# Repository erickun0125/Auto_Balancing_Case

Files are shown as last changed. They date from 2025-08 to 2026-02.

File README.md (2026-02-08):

# Auto Balancing Case

***A self-balancing wheeled suitcase powered by sim-to-real reinforcement learning***







<p align="center">
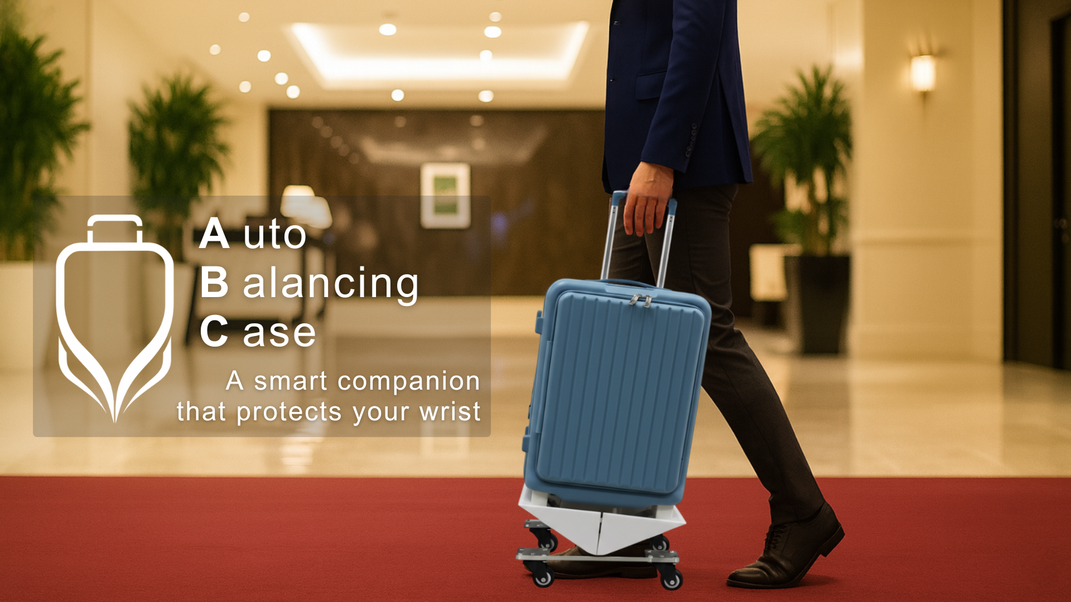
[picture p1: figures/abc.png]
Auto Balancing Case — overview
  
</p>

## Motivation

Conventional wheeled suitcases tilt forward on carpets, ramps, and uneven terrain, forcing users to apply excessive **wrist torque** to keep them upright. This increases fatigue during prolonged travel and makes handling uncomfortable — yet most existing solutions rely on complex vision-based systems or powered wheels that add weight and cost.

This project takes a different approach: instead of fighting gravity with brute force, we **shift the suitcase's center of mass** in real time using a learned policy, eliminating the need for additional user effort entirely.

<p align="center">
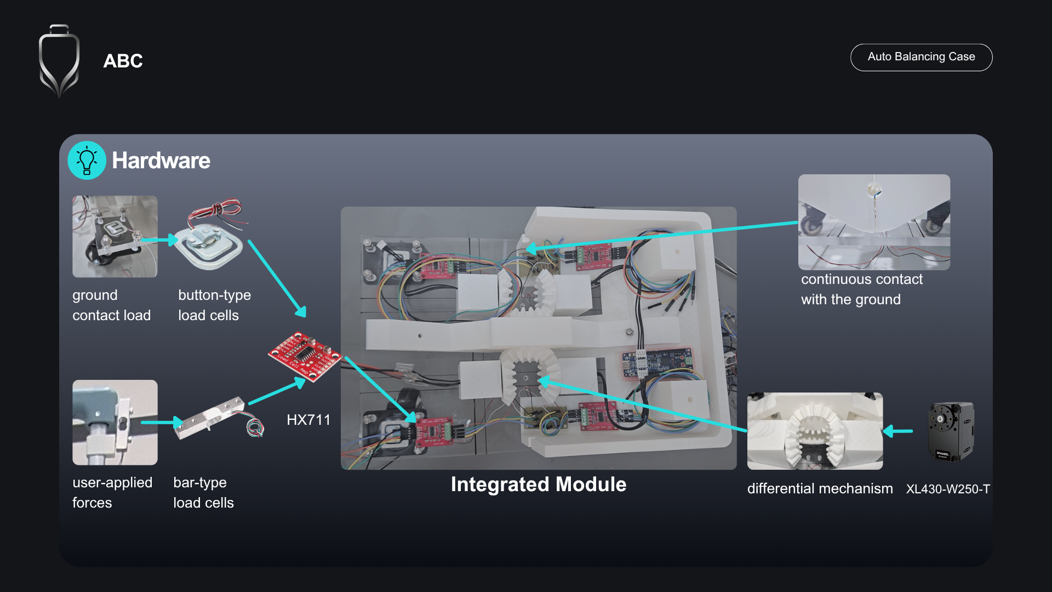
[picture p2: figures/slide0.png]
Presentation slide 1
  
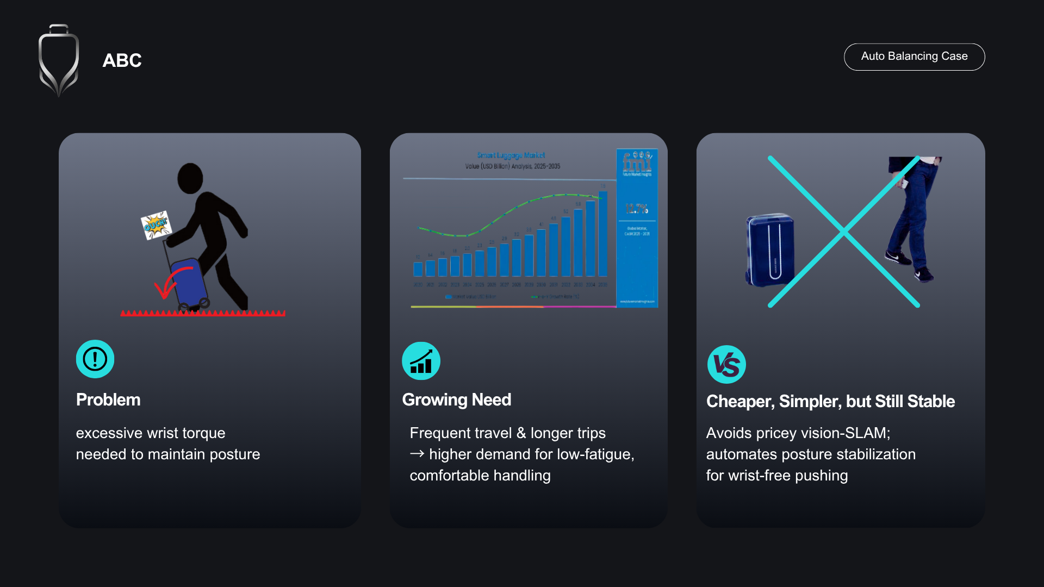
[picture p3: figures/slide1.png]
Presentation slide 2
  
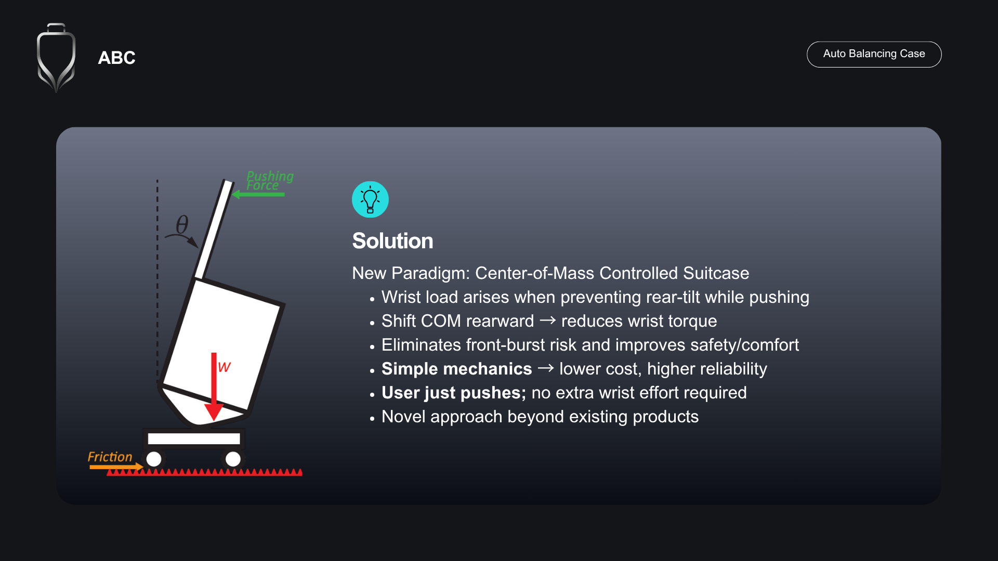
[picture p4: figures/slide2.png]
Presentation slide 3
  
</p>

## Highlights

- **End-to-end pipeline**: CAD design → URDF → Isaac Lab simulation → PPO training → real hardware deployment
- **Sim-to-real transfer** with domain randomization (external forces, velocity pushes, mass variation)
- **Real-time 50 Hz control** with 4 Dynamixel XL430 motors and 5 HX711 load cells
- **Custom reward engineering** with 9 reward terms for contact force balancing
- **2,048 parallel environments**, [256, 128, 64] actor-critic network trained over 15K iterations
- **Multi-sensor fusion**: wheel contact forces + handle force + joint state + action history → 32-dim observation

## Table of Contents

- [Motivation](#motivation)
- [System Overview](#system-overview)
- [Architecture](#architecture)
- [Technical Deep Dive](#technical-deep-dive)
- [Results](#results)
- [Future Work](#future-work)
- [Getting Started](#getting-started)
- [Usage](#usage)
- [Project Structure](#project-structure)
- [Key Specifications](#key-specifications)
- [Contributors](#contributors)
- [Acknowledgments](#acknowledgments)
- [License](#license)

## System Overview

### Core Idea — Mass-Shifting Upper Body

Rather than adding powered wheels or complex stabilization mechanisms, the suitcase features a **mass-shifting upper body** connected to the wheeled base via a single revolute (hinge) joint. When the suitcase begins to tilt — due to a ramp, carpet, or user push — a learned RL policy commands the upper body to shift its center of gravity rearward, **preventing the initial tip and eliminating the wrist torque** the user would otherwise need to apply.

### End-to-End Pipeline

The Auto Balancing Case learns to keep the suitcase upright against external disturbances using this single actuated hinge joint. A PPO policy is trained in NVIDIA Isaac Lab simulation across 2,048 parallel environments, then deployed directly on real hardware via a Python bridge running at 50 Hz — no fine-tuning on real hardware required.

```mermaid
graph LR
    A["CAD Design<br/>SolidWorks"] --> B["URDF Model"]
    B --> C["USD Conversion<br/>Isaac Lab"]
    C --> D["RL Training<br/>PPO / 2048 envs"]
    D --> E["Trained Policy<br/>.pt checkpoint"]
    E --> F["Sim2Real Bridge<br/>Python 50Hz"]
    F --> G["Hardware<br/>4 Motors + 5 Sensors"]
```

## Architecture

### System Architecture

<p align="center">
  System architecture block diagram
</p>

<details>
<summary>Text version (Mermaid)</summary>

```mermaid
graph TB
    subgraph Simulation ["Simulation (Isaac Lab)"]
        ENV["2048 Parallel Envs<br/>PhysX 200Hz"] --> PPO["PPO Training<br/>RSL-RL"]
        PPO --> POLICY["Actor-Critic Network<br/>256 → 128 → 64, ELU"]
    end

    subgraph Bridge ["Sim2Real Bridge (Python)"]
        CONFIG["Config Manager<br/>YAML + Platform Override"] --> CTRL["AutoBalancingCaseBridge<br/>50Hz Control Loop"]
        CTRL --> PI["Policy Interface<br/>PyTorch Inference"]
        CTRL --> MI["Motor Interface<br/>Dynamixel Protocol 2.0"]
        CTRL --> SI["Sensor Interface<br/>Arduino Serial CSV"]
    end

    subgraph Hardware ["Hardware"]
        MI --> MOTORS["4× Dynamixel XL430<br/>2 ports, ±θ"]
        SI --> ARDUINO["Arduino Mega<br/>6× HX711 ADC"]
        ARDUINO --> LC["5 Load Cells<br/>4 wheel + 1 handle"]
    end

    POLICY -.->|".pt checkpoint"| PI
```
</details>

### Observation Space

Each timestep produces an 8-dimensional observation. With 4-step history, the policy sees a **32-dimensional input**.

| Index | Component | Dims | Source | Description |
|---|---|---|---|---|
| 0 | `joint_pos` | 1 | Motor encoder | Relative joint position (rad) |
| 1 | `joint_vel` | 1 | Motor encoder | Joint velocity (rad/s) |
| 2 | `prev_action` | 1 | Policy output | Previous action [−0.5, 0.5] |
| 3–6 | `wheel_forces` | 4 | HX711 load cells | Per-wheel contact force (N) [FR, RR, FL, RL] |
| 7 | `handle_force` | 1 | HX711 load cell | External handle force (N) |

### Reward Engineering

9 reward terms shape the balancing behavior:

| Reward Term | Weight | Type | Purpose |
|---|---|---|---|
| `is_alive` | +1.0 | Bonus | Survival incentive |
| `is_terminated` | −100.0 | Penalty | Large termination punishment |
| `flat_orientation_l2` | −10.0 | Penalty | Keep platform horizontal |
| `ang_vel_xy_l2` | −0.5 | Penalty | Minimize angular oscillation |
| `hinge_pos_deviation` | −5.0 | Penalty | Stay near default joint position |
| `desired_contacts` | −10.0 | Penalty | Maintain all 4 wheel contacts |
| `wheel_contact_balance` | +3.0 | Reward | Equal force distribution (exp(−variance/mean)) |
| `wheel_contact_min_max` | −0.1 | Penalty | Reduce max–min force difference |
| `action_rate_l2` | −0.01 | Penalty | Smooth actions |

## Technical Deep Dive

### Sim-to-Real Transfer

<p align="center">
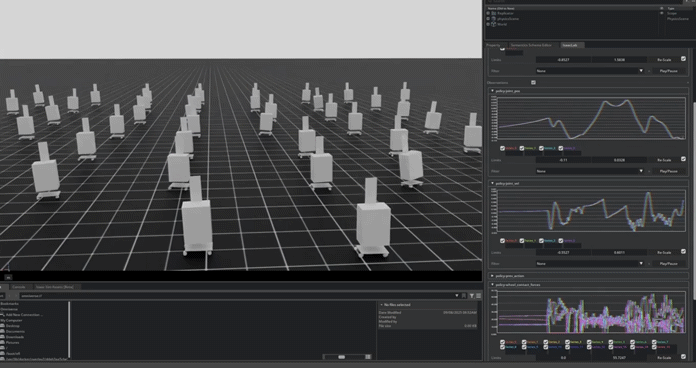
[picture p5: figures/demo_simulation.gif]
Isaac Lab training — 2048 parallel environments
  
  <br/>
  <em>PPO training in NVIDIA Isaac Lab with 2,048 parallel environments</em>
</p>

The policy transfers from simulation to real hardware without fine-tuning. Key strategies:

- **Domain randomization**: 4 disturbance groups applied to partitioned environment subsets
  - Velocity-based pushes (x-axis, randomized range)
  - External wrenches with position offsets
  - Directional force/torque application
  - Combined push + wrench events
- **Raw observations**: No normalization applied — same value ranges in sim and real hardware
- **Observation noise injection**: Additive uniform noise on joint position (±0.005), velocity (±0.05), and forces (±0.01)

### Real-Time Control Pipeline

<p align="center">
  50 Hz real-time control flow
</p>

The 50 Hz control loop in `AutoBalancingCaseBridge` executes 7 steps per cycle (20 ms budget):

1. **Read motor state** — Position and velocity via Dynamixel Protocol 2.0 (2 serial ports)
2. **Read sensor state** — 5 load cell forces via Arduino serial CSV
3. **Construct observation** — 8-dim vector with relative joint position (Isaac Lab compatible)
4. **Update history** — Append to 4-step deque (oldest entries dropped)
5. **Run policy inference** — PyTorch forward pass on 32-dim input (CPU, ~1 ms)
6. **Clip and send command** — Action clipped to [−0.5, 0.5] rad → 4 motors (+θ, +θ, −θ, −θ)
7. **Maintain timing** — Sleep for remainder of 20 ms cycle; warn if >10 ms overrun

**Safety systems**: Emergency stop at 0.51 rad tilt, watchdog timeout at 1.0 s.

### Hardware Design

<p align="center">
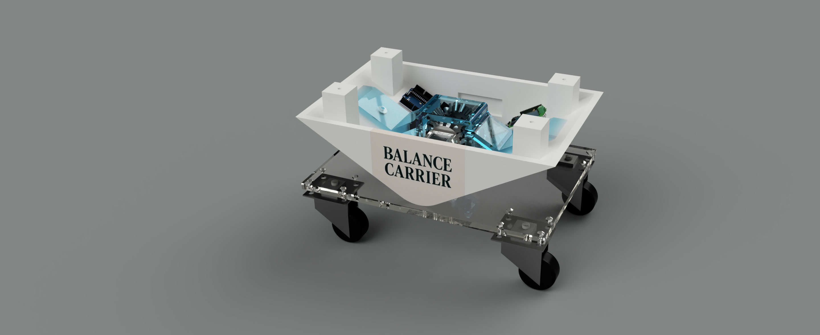
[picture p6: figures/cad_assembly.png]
CAD assembly design
  
</p>

<p align="center">
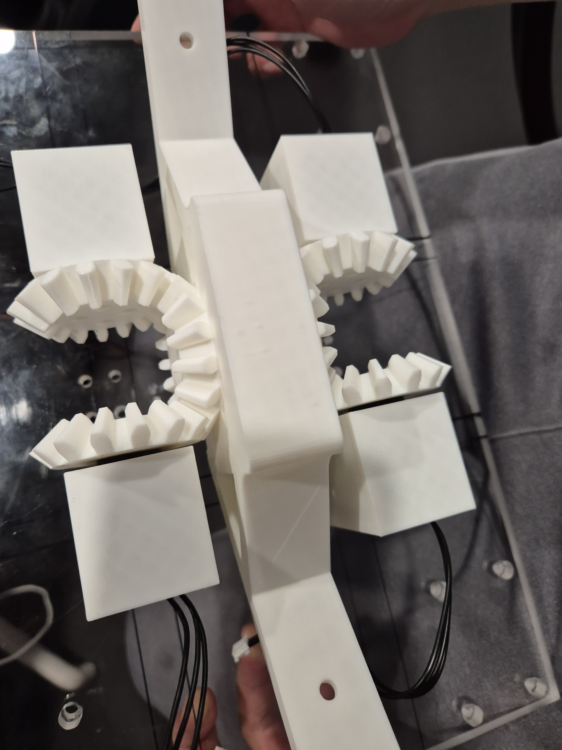
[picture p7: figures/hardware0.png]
Hardware photo 1
  
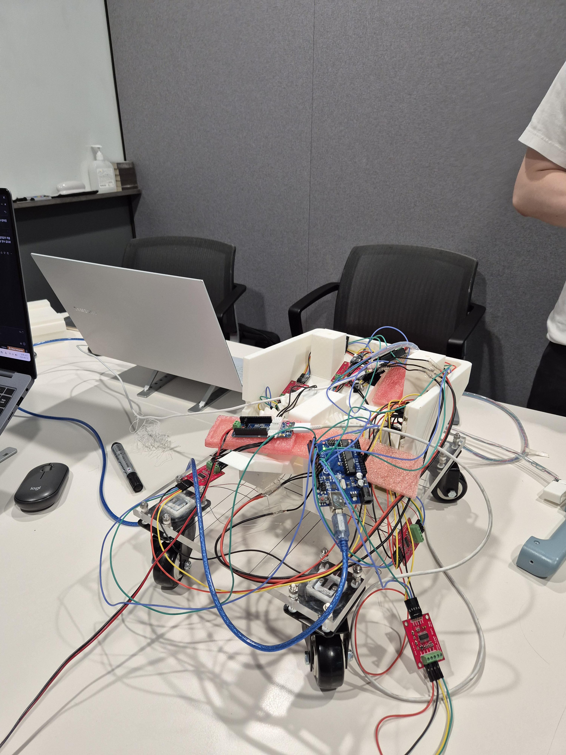
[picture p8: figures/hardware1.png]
Hardware photo 2
  
</p>

<p align="center">
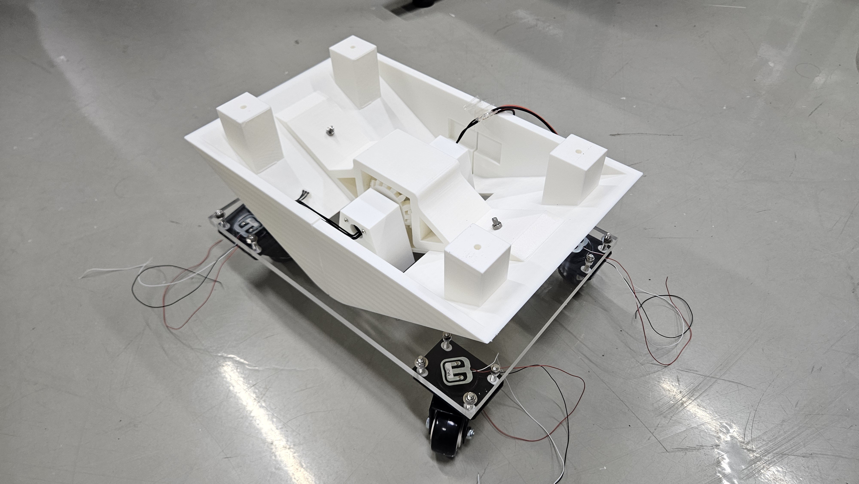
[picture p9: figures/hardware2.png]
Hardware photo 3
  
</p>

- **Base platform**: 4-wheel mobile base (~0.98 kg, 36 cm × 23 cm)
- **Luggage body**: ~5.6 kg connected via single revolute joint (Y-axis, ±30°)
- **Motors**: 4× Dynamixel XL430-W250 (Protocol 2.0, 57600 baud, center=2048)
- **Sensors**: 5× HX711 load cells (4 wheel + 1 handle), Arduino at 115200 baud / 10 Hz
- **Custom parts**: 3D-printed differential bevel gears, motor support, gearbox wing

## Results

<p align="center">
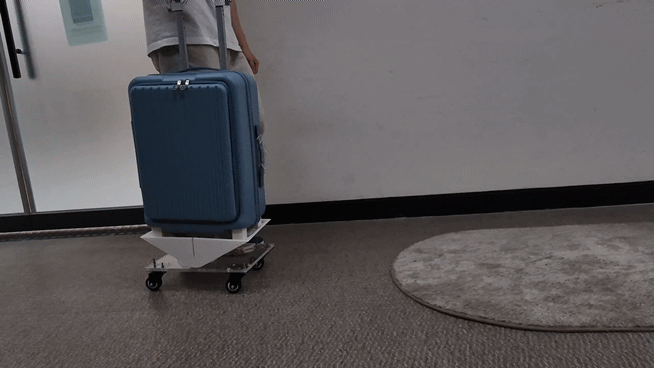
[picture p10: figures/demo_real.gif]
Real hardware demo — self-balancing on uneven terrain
  
  <br/>
  <em>Real-time balancing on uneven terrain — zero additional wrist torque required</em>
</p>

- **Zero additional wrist torque** — users reported no need for extra effort to keep the suitcase upright on rough terrain
- **Responsive disturbance recovery** — the policy reacts to pushes and slope changes within one control cycle (20 ms)
- **Direct sim-to-real transfer** — the trained policy deployed on real hardware without any fine-tuning or adaptation
- **Modular integration** — the mass-shifting mechanism can be integrated into existing suitcase frames without structural redesign

## Future Work

- Quantitative handling-effort measurement (e.g., wrist torque sensor comparison with/without balancing)
- Extension to wheeled carts and logistics platforms
- On-device inference optimization (microcontroller deployment, removing laptop dependency)

## Getting Started

### Prerequisites

- Python 3.8+
- NVIDIA GPU with CUDA (for Isaac Lab training only)
- Dynamixel XL430 motors + Arduino Mega (for hardware deployment)

### Installation

```bash
# Clone the repository
git clone https://github.com/erickun0125/Auto_Balancing_Case.git
cd Auto_Balancing_Case

# Install sim2real bridge dependencies
cd suitcase_sim2real
pip install -r requirements.txt

# Isaac Lab setup (for training only)
# Follow NVIDIA Isaac Lab installation guide, then register custom environments
```

## Usage

### Training (Simulation)

```bash
cd suitcase_learning
./isaaclab.sh -p scripts/train.py --task Isaac-Suitecase-Flat-v0 --num_envs 2048
```

### Evaluation (Simulation)

```bash
./isaaclab.sh -p scripts/play.py --task Isaac-Suitecase-Flat-Play-v0 \
  --checkpoint trained_models/model_49999.pt
```

### Hardware Deployment

```bash
cd suitcase_sim2real/src

# Step 1: Calibrate load cells (first time only)
python run_policy.py --mode calibrate

# Step 2: Run single episode (4000 steps = 8 seconds)
python run_policy.py --mode episode

# Step 3: Run continuously until Ctrl+C
python run_policy.py --mode continuous

# Custom config
python run_policy.py --config path/to/config.yml --mode episode
```

## Project Structure

```
Auto_Balancing_Case/
├── suitcase_learning/               # Isaac Lab simulation & RL training
│   ├── envs/                        #   Custom environment & MDP definitions
│   │   ├── suitecase_env_cfg.py     #     Environment config, rewards, observations
│   │   └── mdp_for_ABC.py           #     Custom MDP functions (forces, events)
│   ├── agents/                      #   PPO hyperparameters
│   │   └── rsl_rl_ppo_cfg.py
│   ├── scripts/                     #   Training & evaluation scripts
│   ├── assets/                      #   USD robot model for Isaac Lab
│   └── trained_models/              #   Checkpoints & exported policies
│
├── suitcase_sim2real/               # Real hardware deployment
│   ├── src/                         #   Main bridge code
│   │   ├── run_policy.py            #     CLI entry point (calibrate/episode/continuous)
│   │   ├── bridge.py                #     50Hz control loop orchestrator
│   │   ├── policy_interface.py      #     RSL-RL model loading & inference
│   │   ├── motor_interface.py       #     4-motor control (2 serial ports)
│   │   ├── sensor_interface.py      #     5 load cell sensor interface
│   │   ├── config_manager.py        #     YAML config with platform overrides
│   │   └── config/interface_config.yml    # All hardware/policy settings
│   ├── firmware/                    #   Arduino firmware (HX711 ADC readout)
│   └── requirements.txt
│
├── suitcase_model/                  # CAD models & URDF robot descriptions
│   ├── urdf/                        #   Robot URDF definitions
│   ├── stl/                         #   3D-printable mechanical parts
│   └── ros_package/                 #   ROS-compatible URDF package
│
├── docs/media/                      # Demo videos, screenshots, diagrams
├── LICENSE
└── README.md
```

## Key Specifications

### Training Configuration

| Parameter | Value |
|---|---|
| Algorithm | PPO (Proximal Policy Optimization) |
| Framework | RSL-RL on NVIDIA Isaac Lab |
| Parallel Environments | 2,048 |
| Physics Frequency | 200 Hz (dt = 0.005 s) |
| Control Frequency | 50 Hz (decimation = 4) |
| Episode Length | 8.0 s (4,000 steps) |
| Network Architecture | Actor & Critic: [256, 128, 64], ELU |
| Observation Dim | 32 (8 per timestep × 4 history) |
| Action Dim | 1 (joint position target, rad) |
| Learning Rate | 1e-3 |
| Max Iterations | 15,000 |
| Discount Factor (γ) | 0.99 |
| GAE Lambda (λ) | 0.95 |

### Hardware Specifications

| Component | Detail |
|---|---|
| Motors | 4× Dynamixel XL430-W250 |
| Motor Protocol | Protocol 2.0, 57600 baud, 2 serial ports |
| Load Cells | 5× HX711 (4 wheel + 1 handle) |
| Sensor MCU | Arduino Mega, 115200 baud, 10 Hz |
| Control Loop | 50 Hz (20 ms cycle) |
| Joint Range | ±0.5 rad (±28.6°) |
| Emergency Stop | 0.51 rad tilt threshold |
| System Mass | ~6.5 kg |

## Contributors

| Name | Contributions |
|---|---|
| **@erickun0125** | IsaacLab Environment Setting, Sim2Real Bridge, RL Agent Training |
| **@toddjrdl** | CAD Model Design, Hardware Integration, Policy Deployment |
| **@juninjae** | Actuator & Sensor System Design, System Integration, Real World Deployment |

## Acknowledgments

- [NVIDIA Isaac Lab](https://isaac-sim.github.io/IsaacLab/) — GPU-accelerated physics simulation & RL framework
- [RSL-RL](https://github.com/leggedrobotics/rsl_rl) — PPO implementation from Robotic Systems Lab (ETH Zurich)
- [Robotis Dynamixel](https://www.robotis.us/) — XL430 motor hardware and SDK
- [PyTorch](https://pytorch.org/) — Neural network framework
- [HX711_ADC](https://github.com/olkal/HX711_ADC) — Arduino load cell library

## License

This project is licensed under the MIT License — see the [LICENSE](LICENSE) file for details.

---

*Built at Seoul National University. Demonstrates a complete robotics development pipeline from concept to real-world deployment.*

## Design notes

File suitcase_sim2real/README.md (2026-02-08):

# Sim2Real Deployment

Deploys the Isaac Lab-trained PPO policy on real Auto Balancing Case hardware at 50 Hz.

## Directory Structure

```
suitcase_sim2real/
├── src/                             # Python bridge code
│   ├── run_policy.py                #   CLI entry point (calibrate/episode/continuous)
│   ├── bridge.py                    #   50 Hz control loop orchestrator
│   ├── policy_interface.py          #   RSL-RL model loading & inference
│   ├── motor_interface.py           #   Dynamixel XL430 motor control (4 motors, 2 ports)
│   ├── sensor_interface.py          #   HX711 load cell interface (5 channels via Arduino)
│   ├── config_manager.py            #   YAML config with platform overrides
│   └── config/interface_config.yml  #   All hardware/policy settings
├── firmware/                        # Arduino firmware
│   └── hx711_load_cells/
│       └── hx711_load_cells.ino     #   6× HX711 ADC readout, CSV at 10 Hz
└── requirements.txt                 # Python dependencies
```

## Hardware

| Component | Details |
|---|---|
| Motors | 4× Dynamixel XL430-W250, Protocol 2.0, 57600 baud, 2 serial ports |
| Sensors | 5× HX711 load cells (4 wheel + 1 handle), Arduino Mega, 115200 baud |
| Control | 50 Hz real-time loop, ±0.5 rad action range, 0.51 rad emergency stop |

## Quick Start

```bash
cd src
pip install -r ../requirements.txt

python run_policy.py --mode calibrate    # First-time load cell calibration
python run_policy.py --mode episode      # Single episode (8 seconds)
python run_policy.py --mode continuous   # Run until Ctrl+C
```

## Platform Configuration

Serial ports are auto-configured via `platform_overrides` in `config/interface_config.yml`:
- **Windows**: COM7 (sensor), COM11/COM12 (motors)
- **Linux**: /dev/ttyACM0 (sensor), /dev/ttyUSB0/ttyUSB1 (motors)

## Safety

- Emergency stop at 0.51 rad tilt threshold
- Watchdog timeout at 1.0 second
- Motors return to center position on shutdown
- Torque disabled after safe stop

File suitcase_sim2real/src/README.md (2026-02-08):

# Sim2Real Bridge — Source Code

This directory contains the Python bridge that deploys the Isaac Lab-trained RL policy on real hardware at 50 Hz.

## Files

| File | Description |
|---|---|
| `run_policy.py` | CLI entry point (`calibrate`, `episode`, `continuous` modes) |
| `bridge.py` | Main 50 Hz control loop orchestrator |
| `policy_interface.py` | RSL-RL ActorCritic model loading and inference |
| `motor_interface.py` | Dynamixel XL430 motor control (4 motors, 2 serial ports) |
| `sensor_interface.py` | HX711 load cell sensor interface (5 channels via Arduino) |
| `config_manager.py` | YAML configuration loader with platform overrides |
| `config/interface_config.yml` | Hardware and policy configuration |

## Quick Start

```bash
# Install dependencies
pip install -r ../requirements.txt

# Calibrate load cells (first time only)
python run_policy.py --mode calibrate

# Run single episode (4000 steps = 8 seconds)
python run_policy.py --mode episode

# Run continuously until Ctrl+C
python run_policy.py --mode continuous
```

See the [project README](../../README.md) for full documentation.

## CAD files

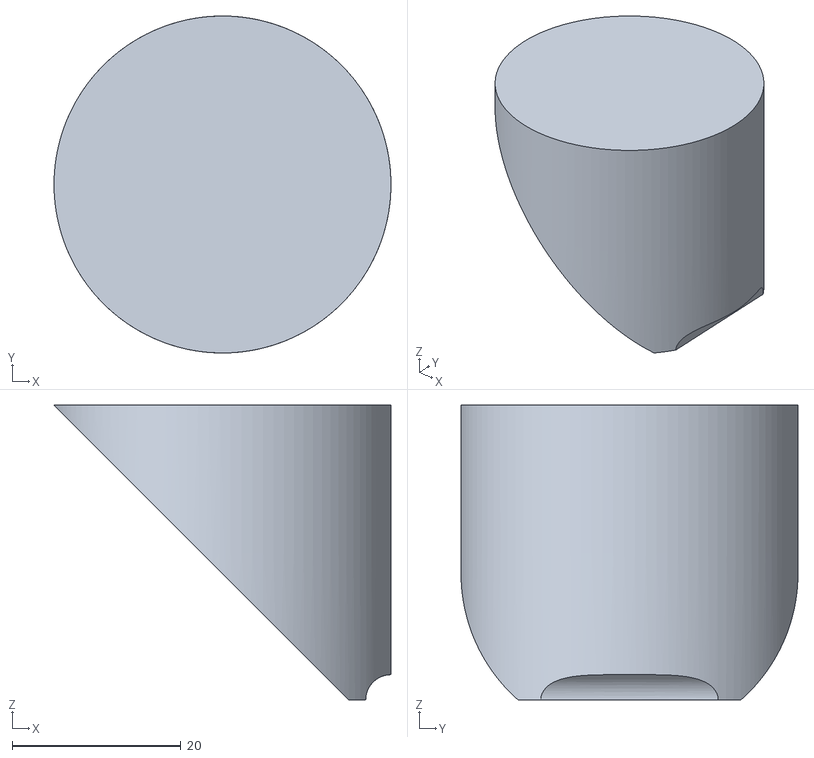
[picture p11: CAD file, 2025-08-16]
suitcase_model/ros_package/meshes/FR_wheelbase_1.stl
40.0 x 40.0 x 35.0

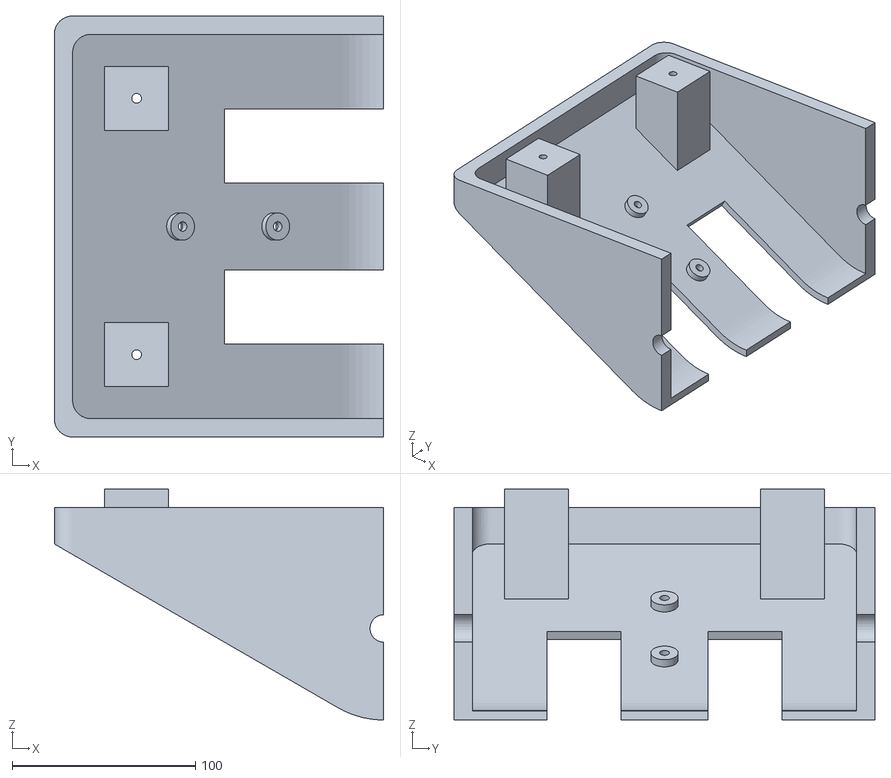
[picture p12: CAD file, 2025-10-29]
suitcase_model/stl/bottom_half.stl
180.0 x 230.0 x 126.2

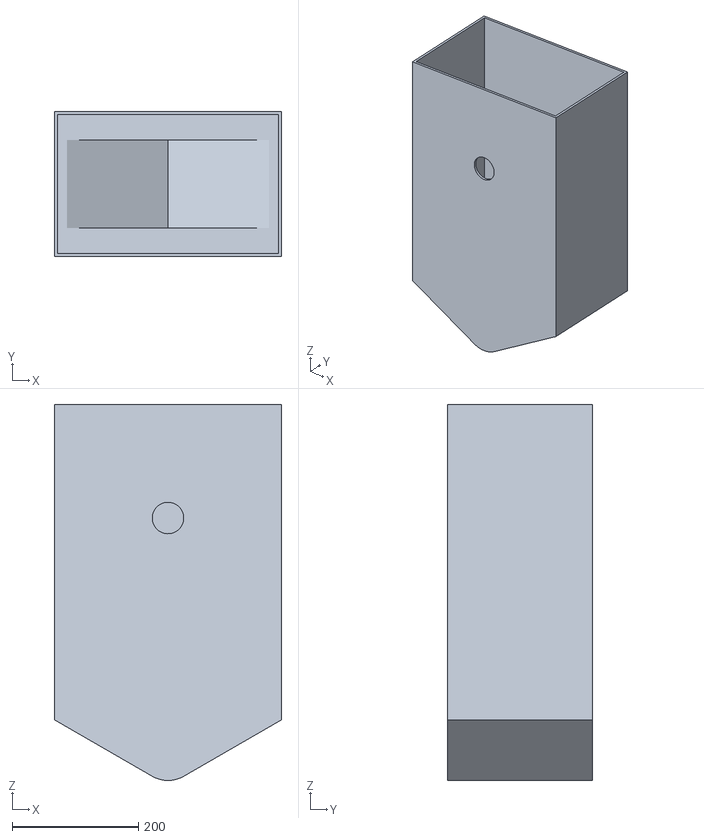
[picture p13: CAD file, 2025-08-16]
suitcase_model/ros_package/meshes/luggage_case_1.stl
360.0 x 230.0 x 596.2

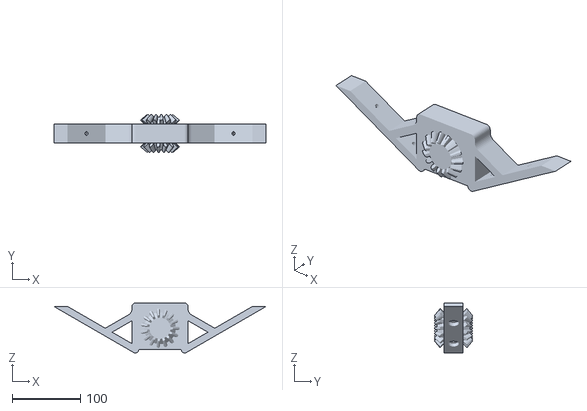
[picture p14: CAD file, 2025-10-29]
suitcase_model/stl/gearbox_wing.stl
309.9 x 55.0 x 73.0

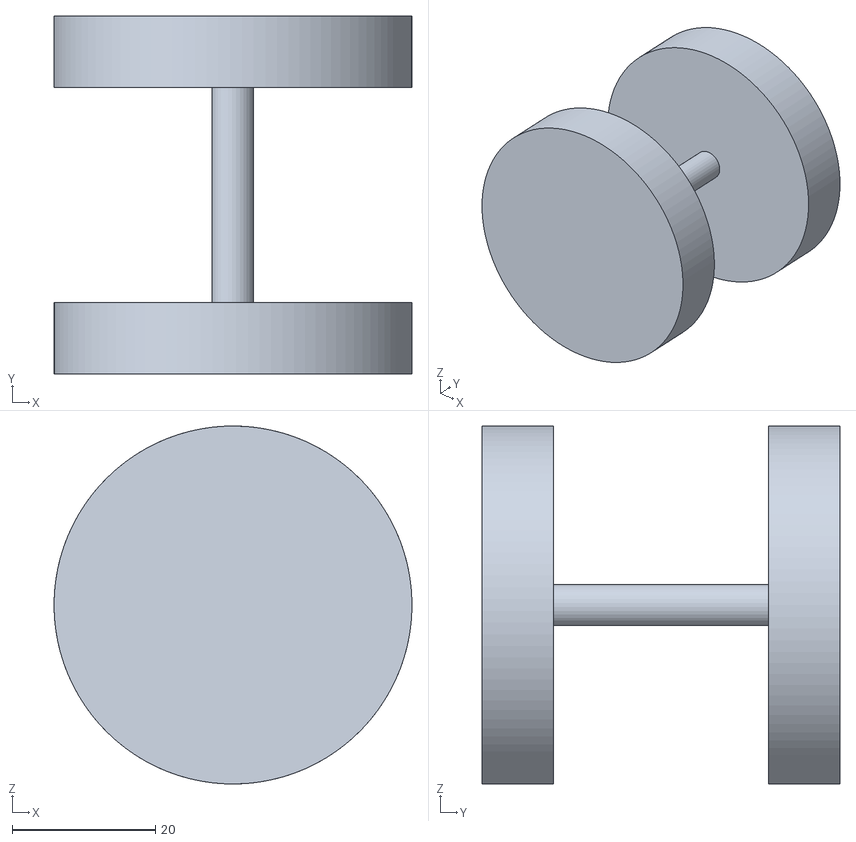
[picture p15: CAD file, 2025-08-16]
suitcase_model/ros_package/meshes/FL_wheel_1.stl
50.0 x 50.0 x 50.0

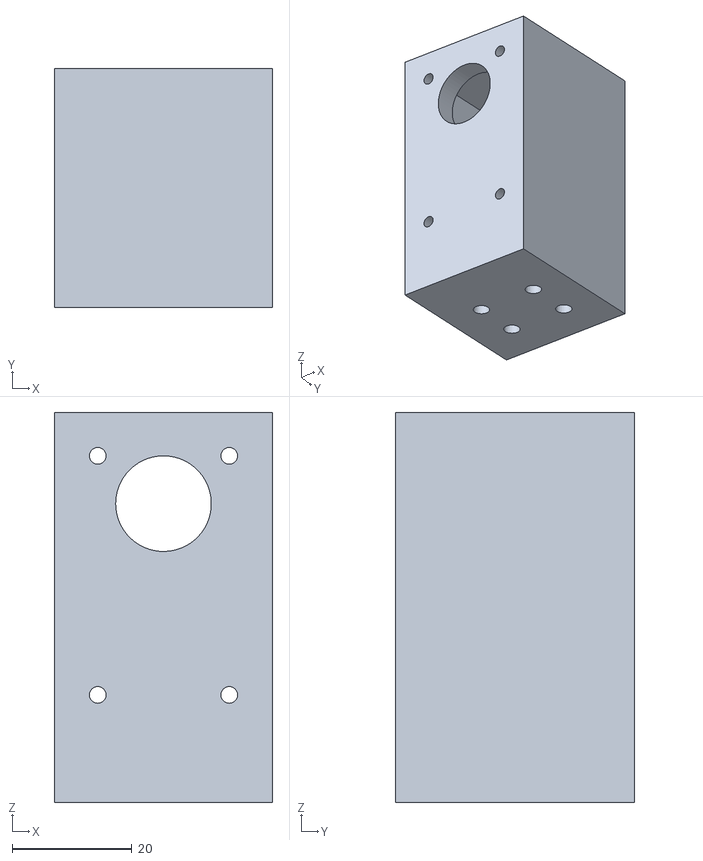
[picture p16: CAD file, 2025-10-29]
suitcase_model/stl/motor_support.stl
36.5 x 40.0 x 65.2

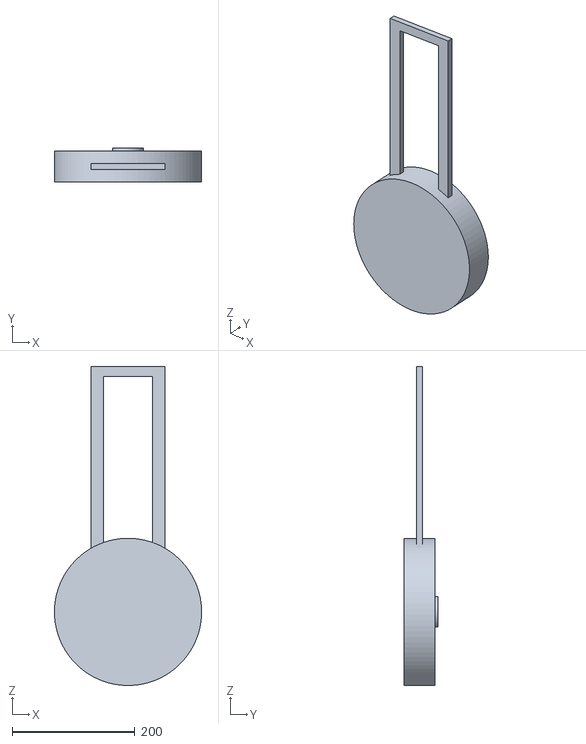
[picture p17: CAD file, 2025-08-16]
suitcase_model/ros_package/meshes/rotating_handle_1.stl
239.9 x 55.0 x 520.0

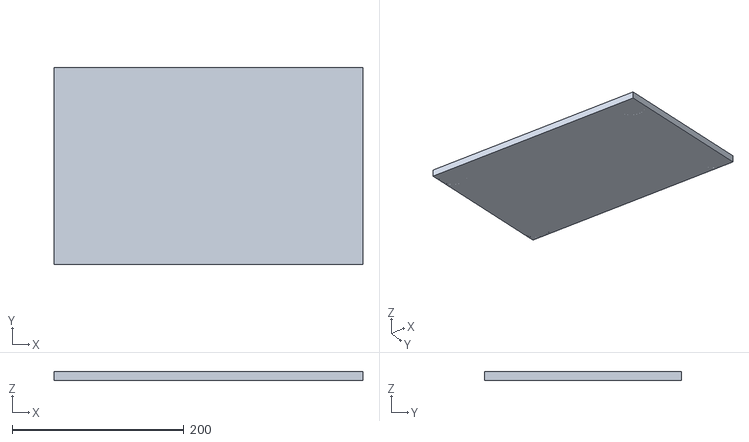
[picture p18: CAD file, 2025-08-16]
suitcase_model/ros_package/meshes/base_link.stl
360.0 x 230.0 x 10.0

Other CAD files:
suitcase_model/ros_package/meshes/FL_wheelbase_1.stl
suitcase_model/ros_package/meshes/RL_wheelbase_1.stl
suitcase_model/ros_package/meshes/RL_wheel_1.stl
suitcase_model/ros_package/meshes/RR_wheel_1.stl
suitcase_model/ros_package/meshes/RR_wheelbase_1.stl
suitcase_model/ros_package/meshes/FR_wheel_1.stl

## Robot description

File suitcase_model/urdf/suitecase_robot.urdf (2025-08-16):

<?xml version="1.0" ?>
<robot name="Auto_Balancing_Case" xmlns:xacro="http://www.ros.org/wiki/xacro">

  <!-- simple inline material since xacro includes are removed -->
  <material name="silver">
    <color rgba="0.75 0.75 0.75 1.0"/>
  </material>

  
<link name="base_link">
  <inertial>
    <origin xyz="0.17999999999999997 0.115 0.005003006827026274" rpy="0 0 0"/>
    <mass value="0.9847218407587564"/>
    <inertia ixx="0.004346" iyy="0.010634" izz="0.014964" ixy="-0.0" iyz="0.0" ixz="-0.0"/>
  </inertial>
  <visual>
    <origin xyz="0.18 0.115 0.005" rpy="0 0 0"/>
    <geometry>
      <box size="0.36 0.23 0.01"/>
    </geometry>
    <material name="silver"/>
  </visual>
  <collision>
    <origin xyz="0.18 0.115 0.005" rpy="0 0 0"/>
    <geometry>
      <box size="0.36 0.23 0.01"/>
    </geometry>
  </collision>
</link>

<link name="handle">
  <inertial>
    <origin xyz="0.0 0.0 0.0" rpy="0 0 0"/>
    <mass value="0.0"/>
    <inertia ixx="0.0" iyy="0.0" izz="0.0" ixy="-0.0" iyz="0.0" ixz="-0.0"/>
  </inertial>
  <visual>
    <origin xyz="0.0 0.005 0.35" rpy="0 0 0"/>
    <geometry>
      <box size="0.15 0.01 0.35"/>
    </geometry>
    <material name="silver"/>
  </visual>
  <collision>
    <origin xyz="0.0 0.005 0.35" rpy="0 0 0"/>
    <geometry>
      <box size="0.15 0.01 0.35"/>
    </geometry>
  </collision>
</link>

<link name="FR_wheelbase_1">
  <inertial>
    <origin xyz="0.004854891037663869 0.0 -0.01224396424044122" rpy="0 0 0"/>
    <mass value="0.026348088954006088"/>
    <inertia ixx="5e-06" iyy="4e-06" izz="5e-06" ixy="-0.0" iyz="0.0" ixz="1e-06"/>
  </inertial>
</link>

<link name="RR_wheelbase_1">
  <inertial>
    <origin xyz="0.004821350892733667 -2.7755575615628914e-17 -0.012195503618703826" rpy="0 0 0"/>
    <mass value="0.02614973311170209"/>
    <inertia ixx="5e-06" iyy="4e-06" izz="5e-06" ixy="-0.0" iyz="0.0" ixz="1e-06"/>
  </inertial>
</link>

<link name="FL_wheelbase_1">
  <inertial>
    <origin xyz="0.0048548910376638756 -1.0408340855860843e-17 -0.012243964240441205" rpy="0 0 0"/>
    <mass value="0.02634808895400608"/>
    <inertia ixx="5e-06" iyy="4e-06" izz="5e-06" ixy="-0.0" iyz="-0.0" ixz="1e-06"/>
  </inertial>
</link>

<link name="RL_wheelbase_1">
  <inertial>
    <origin xyz="0.004821350892733667 -2.7755575615628914e-17 -0.012195503618703807" rpy="0 0 0"/>
    <mass value="0.02614973311170209"/>
    <inertia ixx="5e-06" iyy="4e-06" izz="5e-06" ixy="-0.0" iyz="-0.0" ixz="1e-06"/>
  </inertial>
</link>

<link name="FL_wheel_1">
  <inertial>
    <origin xyz="5.988265439071938e-15 -3.469446951953614e-18 1.3877787807814457e-17" rpy="0 0 0"/>
    <mass value="0.04246628391615553"/>
    <inertia ixx="2.4e-05" iyy="1.3e-05" izz="2.4e-05" ixy="-0.0" iyz="0.0" ixz="0.0"/>
  </inertial>
  <visual>
    <origin xyz="0 0 0" rpy="-1.5708 0 0"/>
    <geometry>
      <cylinder radius="0.025" length="0.05"/>
    </geometry>
    <material name="silver"/>
  </visual>
  <collision>
    <origin xyz="0 0 0" rpy="-1.5708 0 0"/>
    <geometry>
      <cylinder radius="0.025" length="0.05"/>
    </geometry>
  </collision>
</link>

<link name="RR_wheel_1">
  <inertial>
    <origin xyz="-1.3006670518400654e-07 0.0 -2.0816681711721685e-17" rpy="0 0 0"/>
    <mass value="0.042466283916155555"/>
    <inertia ixx="2.4e-05" iyy="1.3e-05" izz="2.4e-05" ixy="0.0" iyz="-0.0" ixz="0.0"/>
  </inertial>
  <visual>
    <origin xyz="0 0 0" rpy="-1.5708 0 0"/>
    <geometry>
      <cylinder radius="0.025" length="0.05"/>
    </geometry>
    <material name="silver"/>
  </visual>
  <collision>
    <origin xyz="0 0 0" rpy="-1.5708 0 0"/>
    <geometry>
      <cylinder radius="0.025" length="0.05"/>
    </geometry>
  </collision>
</link>

<link name="FR_wheel_1">
  <inertial>
    <origin xyz="6.0021432268797525e-15 0.0 1.3877787807814457e-17" rpy="0 0 0"/>
    <mass value="0.04246628391615553"/>
    <inertia ixx="2.4e-05" iyy="1.3e-05" izz="2.4e-05" ixy="0.0" iyz="0.0" ixz="0.0"/>
  </inertial>
  <visual>
    <origin xyz="0 0 0" rpy="-1.5708 0 0"/>
    <geometry>
      <cylinder radius="0.025" length="0.05"/>
    </geometry>
    <material name="silver"/>
  </visual>
  <collision>
    <origin xyz="0 0 0" rpy="-1.5708 0 0"/>
    <geometry>
      <cylinder radius="0.025" length="0.05"/>
    </geometry>
  </collision>
</link>

<link name="RL_wheel_1">
  <inertial>
    <origin xyz="-1.3006670512849539e-07 6.245004513516506e-17 0.0" rpy="0 0 0"/>
    <mass value="0.042466283916155555"/>
    <inertia ixx="2.4e-05" iyy="1.3e-05" izz="2.4e-05" ixy="-0.0" iyz="0.0" ixz="0.0"/>
  </inertial>
  <visual>
    <origin xyz="0 0 0" rpy="-1.5708 0 0"/>
    <geometry>
      <cylinder radius="0.025" length="0.05"/>
    </geometry>
    <material name="silver"/>
  </visual>
  <collision>
    <origin xyz="0 0 0" rpy="-1.5708 0 0"/>
    <geometry>
      <cylinder radius="0.025" length="0.05"/>
    </geometry>
  </collision>
</link>

<link name="luggage_case_1">
  <inertial>
    <origin xyz="1.0107192860431269e-12 0.1113836158375588 0.19099105534572558" rpy="0 0 0"/>
    <mass value="5.601340756429785"/>
    <inertia ixx="0.281154" iyy="0.307224" izz="0.120645" ixy="-0.0" iyz="0.010699" ixz="0.0"/>
  </inertial>
  <visual>
    <origin xyz="0.0 0.115 0.29688" rpy="0 0 0"/>
    <geometry>
      <box size="0.36 0.23 0.5"/>
    </geometry>
    <material name="silver"/>
  </visual>
  <collision>
    <origin xyz="0.0 0.115 0.29688" rpy="0 0 0"/>
    <geometry>
      <box size="0.36 0.23 0.5"/>
    </geometry>
  </collision>
</link>

<joint name="Revolute 1" type="continuous">
  <origin xyz="0.02 0.21 0.0001" rpy="0 0 0"/>
  <parent link="base_link"/>
  <child link="FR_wheelbase_1"/>
  <axis xyz="0.0 0.0 -1.0"/>
</joint>

<joint name="Revolute 2" type="continuous">
  <origin xyz="0.34 0.21 0.0001" rpy="0 0 0"/>
  <parent link="base_link"/>
  <child link="RR_wheelbase_1"/>
  <axis xyz="0.0 0.0 -1.0"/>
</joint>

<joint name="Revolute 3" type="continuous">
  <origin xyz="0.02 0.02 0.0001" rpy="0 0 0"/>
  <parent link="base_link"/>
  <child link="FL_wheelbase_1"/>
  <axis xyz="0.0 0.0 -1.0"/>
</joint>

<joint name="Revolute 4" type="continuous">
  <origin xyz="0.34 0.02 0.0001" rpy="0 0 0"/>
  <parent link="base_link"/>
  <child link="RL_wheelbase_1"/>
  <axis xyz="0.0 0.0 -1.0"/>
</joint>

<joint name="Revolute 5" type="continuous">
  <origin xyz="0.02 0.0 -0.035" rpy="0 0 0"/>
  <parent link="FL_wheelbase_1"/>
  <child link="FL_wheel_1"/>
  <axis xyz="0.0 1.0 0.0"/>
</joint>

<joint name="Revolute 6" type="continuous">
  <origin xyz="0.01992 0.0 -0.035" rpy="0 0 0"/>
  <parent link="RR_wheelbase_1"/>
  <child link="RR_wheel_1"/>
  <axis xyz="0.0 1.0 0.0"/>
</joint>

<joint name="Revolute 7" type="continuous">
  <origin xyz="0.02 0.0 -0.035" rpy="0 0 0"/>
  <parent link="FR_wheelbase_1"/>
  <child link="FR_wheel_1"/>
  <axis xyz="0.0 1.0 0.0"/>
</joint>

<joint name="Revolute 8" type="continuous">
  <origin xyz="0.01992 0.0 -0.035" rpy="0 0 0"/>
  <parent link="RL_wheelbase_1"/>
  <child link="RL_wheel_1"/>
  <axis xyz="0.0 1.0 0.0"/>
</joint>

  <joint name="Revolute_motor" type="revolute">
    <origin xyz="0.18 0.0 0.06" rpy="0 0 0"/>
    <parent link="base_link"/>
    <child link="luggage_case_1"/>
    <axis xyz="0.0 -1.0 0.0"/>
    <limit lower="-0.5236" upper="0.5236" effort="3.0" velocity="6.2832"/>
  </joint>

<joint name="Fixed_handle" type="fixed">
  <origin xyz="0.0 -0.0 0.366188" rpy="0 0 0"/>
  <parent link="luggage_case_1"/>
  <child link="handle"/>
  <axis xyz="0.0 0.0 0.0"/>
</joint>

</robot>

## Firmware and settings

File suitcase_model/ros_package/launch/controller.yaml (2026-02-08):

assembly_final_urdf_controller:
  # Publish all joint states -----------------------------------
  joint_state_controller:
    type: joint_state_controller/JointStateController
    publish_rate: 50

  # Position Controllers --------------------------------------
  Revolute 1_position_controller:
    type: effort_controllers/JointPositionController
    joint: Revolute 1
    pid: {p: 100.0, i: 0.01, d: 10.0}
  Revolute 2_position_controller:
    type: effort_controllers/JointPositionController
    joint: Revolute 2
    pid: {p: 100.0, i: 0.01, d: 10.0}
  Revolute 3_position_controller:
    type: effort_controllers/JointPositionController
    joint: Revolute 3
    pid: {p: 100.0, i: 0.01, d: 10.0}
  Revolute 4_position_controller:
    type: effort_controllers/JointPositionController
    joint: Revolute 4
    pid: {p: 100.0, i: 0.01, d: 10.0}
  Revolute 5_position_controller:
    type: effort_controllers/JointPositionController
    joint: Revolute 5
    pid: {p: 100.0, i: 0.01, d: 10.0}
  Revolute 6_position_controller:
    type: effort_controllers/JointPositionController
    joint: Revolute 6
    pid: {p: 100.0, i: 0.01, d: 10.0}
  Revolute 7_position_controller:
    type: effort_controllers/JointPositionController
    joint: Revolute 7
    pid: {p: 100.0, i: 0.01, d: 10.0}
  Revolute 8_position_controller:
    type: effort_controllers/JointPositionController
    joint: Revolute 8
    pid: {p: 100.0, i: 0.01, d: 10.0}
  Revolute_motor_position_controller:
    type: effort_controllers/JointPositionController
    joint: Revolute_motor
    pid: {p: 100.0, i: 0.01, d: 10.0}
  Revolute_handle_position_controller:
    type: effort_controllers/JointPositionController
    joint: Revolute_handle
    pid: {p: 100.0, i: 0.01, d: 10.0}

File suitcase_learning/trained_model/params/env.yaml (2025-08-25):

viewer:
  eye: !!python/tuple
  - 7.5
  - 7.5
  - 7.5
  lookat: !!python/tuple
  - 0.0
  - 0.0
  - 0.0
  cam_prim_path: /OmniverseKit_Persp
  resolution: !!python/tuple
  - 1280
  - 720
  origin_type: world
  env_index: 0
  asset_name: null
  body_name: null
sim:
  physics_prim_path: /physicsScene
  device: cuda:0
  dt: 0.005
  render_interval: 4
  gravity: !!python/tuple
  - 0.0
  - 0.0
  - -9.81
  enable_scene_query_support: false
  use_fabric: true
  physx:
    solver_type: 1
    min_position_iteration_count: 1
    max_position_iteration_count: 255
    min_velocity_iteration_count: 0
    max_velocity_iteration_count: 255
    enable_ccd: false
    enable_stabilization: false
    enable_enhanced_determinism: false
    bounce_threshold_velocity: 0.5
    friction_offset_threshold: 0.04
    friction_correlation_distance: 0.025
    gpu_max_rigid_contact_count: 8388608
    gpu_max_rigid_patch_count: 163840
    gpu_found_lost_pairs_capacity: 2097152
    gpu_found_lost_aggregate_pairs_capacity: 33554432
    gpu_total_aggregate_pairs_capacity: 2097152
    gpu_collision_stack_size: 67108864
    gpu_heap_capacity: 67108864
    gpu_temp_buffer_capacity: 16777216
    gpu_max_num_partitions: 8
    gpu_max_soft_body_contacts: 1048576
    gpu_max_particle_contacts: 1048576
  physics_material:
    func: isaaclab.sim.spawners.materials.physics_materials:spawn_rigid_body_material
    static_friction: 1.0
    dynamic_friction: 1.0
    restitution: 0.0
    improve_patch_friction: true
    friction_combine_mode: average
    restitution_combine_mode: average
    compliant_contact_stiffness: 0.0
    compliant_contact_damping: 0.0
  render:
    enable_translucency: null
    enable_reflections: null
    enable_global_illumination: null
    antialiasing_mode: null
    enable_dlssg: null
    enable_dl_denoiser: null
    dlss_mode: null
    enable_direct_lighting: null
    samples_per_pixel: null
    enable_shadows: null
    enable_ambient_occlusion: null
    carb_settings: null
    rendering_mode: null
ui_window_class_type: isaaclab.envs.ui.manager_based_rl_env_window:ManagerBasedRLEnvWindow
seed: 42
decimation: 4
scene:
  num_envs: 4096
  env_spacing: 3.0
  lazy_sensor_update: true
  replicate_physics: true
  filter_collisions: true
  robot:
    class_type: isaaclab.assets.articulation.articulation:Articulation
    prim_path: /World/envs/env_.*/Robot
    spawn:
      func: isaaclab.sim.spawners.from_files.from_files:spawn_from_usd
      visible: true
      semantic_tags: null
      copy_from_source: true
      mass_props: null
      deformable_props: null
      rigid_props:
        rigid_body_enabled: null
        kinematic_enabled: null
        disable_gravity: false
        linear_damping: null
        angular_damping: null
        max_linear_velocity: null
        max_angular_velocity: null
        max_depenetration_velocity: 5.0
        max_contact_impulse: null
        enable_gyroscopic_forces: null
        retain_accelerations: null
        solver_position_iteration_count: null
        solver_velocity_iteration_count: null
        sleep_threshold: null
        stabilization_threshold: null
      collision_props: null
      activate_contact_sensors: true
      scale: null
      articulation_props:
        articulation_enabled: null
        enabled_self_collisions: true
        solver_position_iteration_count: 8
        solver_velocity_iteration_count: 0
        sleep_threshold: null
        stabilization_threshold: null
        fix_root_link: null
      fixed_tendons_props: null
      joint_drive_props: null
      visual_material_path: material
      visual_material: null
      usd_path: /home/eric/sequor_robotics/sequor_sim/IsaacLab/source/isaaclab_tasks/isaaclab_tasks/manager_based/suitecase/assets/Auto_Balancing_Case.usda
      variants: null
    init_state:
      pos: !!python/tuple
      - 0.0
      - 0.0
      - 0.15
      rot: !!python/tuple
      - 1.0
      - 0.0
      - 0.0
      - 0.0
      lin_vel: !!python/tuple
      - 0.0
      - 0.0
      - 0.0
      ang_vel: !!python/tuple
      - 0.0
      - 0.0
      - 0.0
      joint_pos:
        .*: 0.0
      joint_vel:
        .*: 0.0
    collision_group: 0
    debug_vis: false
    articulation_root_prim_path: null
    soft_joint_pos_limit_factor: 1.0
    actuators:
      balance_hinge:
        class_type: isaaclab.actuators.actuator_pd:ImplicitActuator
        joint_names_expr:
        - Revolute_motor
        effort_limit: null
        velocity_limit: null
        effort_limit_sim: 3.0
        velocity_limit_sim: 6
        stiffness: 10.0
        damping: 1.0
        armature: null
        friction: null
    actuator_value_resolution_debug_print: false
  wheel_contact_forces:
    class_type: isaaclab.sensors.contact_sensor.contact_sensor:ContactSensor
    prim_path: /World/envs/env_.*/Robot/Auto_Balancing_Case/.*_wheel_1
    update_period: 0.005
    history_length: 3
    debug_vis: false
    track_pose: false
    track_air_time: true
    force_threshold: 1.0
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

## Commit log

2025-08-16 [init] initialize Auto_Balancing_Case RL Env
    [FL_wheel_1.stl, FL_wheelbase_1.stl, FR_wheel_1.stl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]
2025-08-16 [model] update usda file - edit joint features(stiffenss, damping, inertia)
2025-08-16 [model] update usda file : must set damping for joints
2025-08-20 [checkpoint] update repo structure
    [iniconfig-license.txt, lula_franka_gen.urdf, simple_2_link.urdf]
2025-08-20 [checkpoint] initialize Sim2Real
    [lula_franka_gen.urdf, simple_2_link.urdf]
2025-08-20 Add HX711 sensor library for load cell interface
2025-08-23 [feat] update Sim2Real : use 2 motors and use arduino for hx711
2025-09-07 [feat] update max torque
2025-09-08 [feat] update motor interface - 4 motors
2025-09-08 [feat] update sensor interface
2025-09-08 [feat] 2 port for 4 motor
2025-09-13 [checkpoint] arduino ino & src files
2025-09-13 [feat] resolve multi port issues
    [config_manager.py]
2025-10-29 Create STL

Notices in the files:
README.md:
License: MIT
